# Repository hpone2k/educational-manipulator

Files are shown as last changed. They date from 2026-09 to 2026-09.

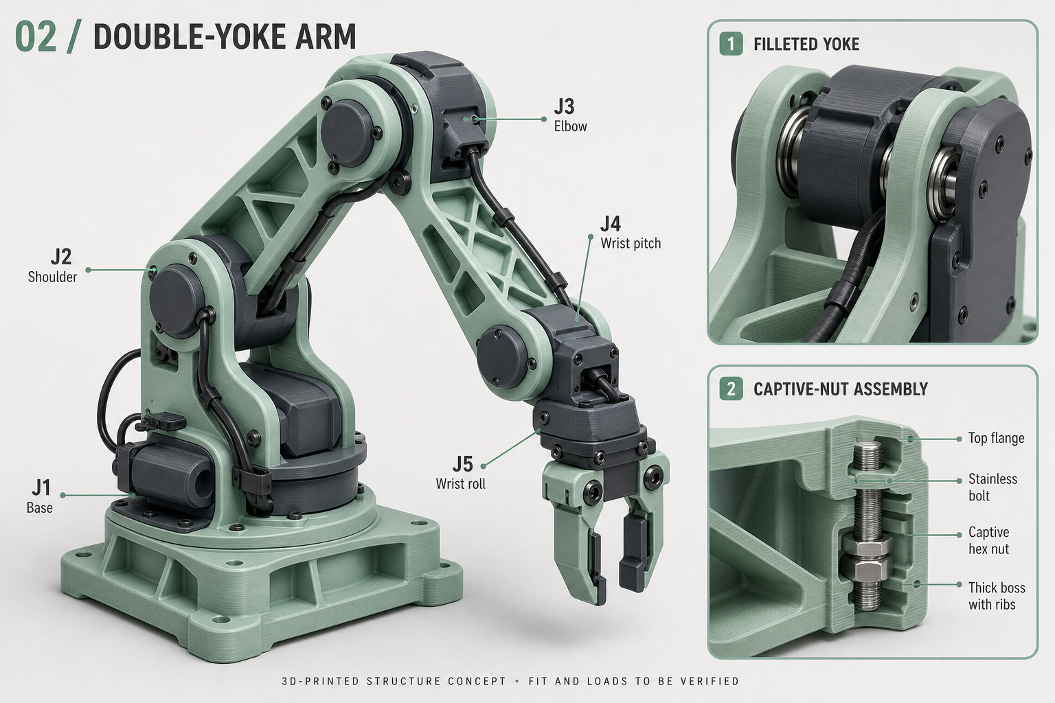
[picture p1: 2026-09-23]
design-concepts/plastic/02-double-yoke.png

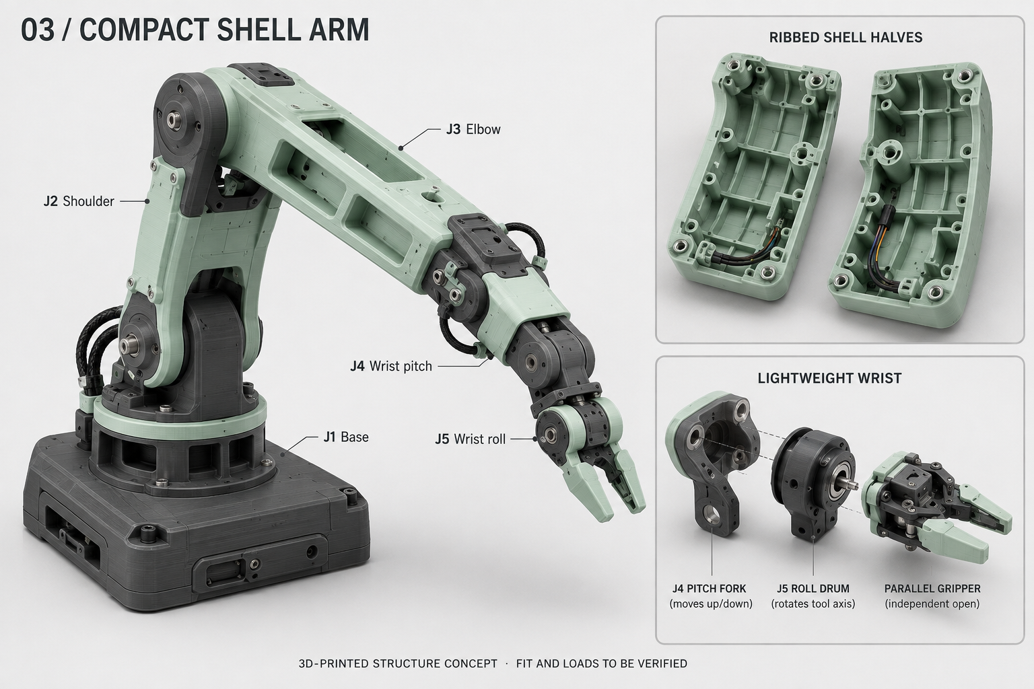
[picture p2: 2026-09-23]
design-concepts/plastic/03-compact-shell.png

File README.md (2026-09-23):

# Educational Manipulator — Blender & Web Studio

The latest mechanical prototype is **EDU06 R06**, with four AX-12A motors, two XM430-W350-T motors, five arm axes and a powered gripper. It includes paired joint supports, centred links, an enlarged electronics base and a modelled daisy-chain harness.

- [Blender assembly](cad/blender-edu06-r06/EDU06_R06.blend)
- [Complete R06 package: model, 186 STL files, previews and reports](cad/blender-edu06-r06/EDU06_R06_Blender_and_Print_Prototype.zip)
- [Assembly, dimensions and printing guide](cad/blender-edu06-r06/README.md)
- [Mechanical verification and limitations](cad/blender-edu06-r06/engineering-review.md)
- [Wiring and connector notes](cad/blender-edu06-r06/wiring-notes.md)

R06 has sampled digital geometry, motion and cable checks. Physical print fits, cable retention and load capacity still require validation. Earlier CAD revisions are retained in `cad/`; temporary generation files and local runtime caches are excluded from Git.

## Orbit web concept

The web application below is an earlier interactive concept. Its illustrative dimensions are separate from the R06 manufacturing prototype.

A local web application for exploring a five-joint educational robot arm. The interface includes a detailed 3D model, selectable joint labels, joint angle controls, a parallel gripper, preset poses, a 12-second motion demonstration, camera views and live tool coordinates.

## Run

With Node.js installed, open a terminal in this folder and run:

```sh
npm start
```

Open http://127.0.0.1:4173 in a browser with WebGL 2 support. Keep the terminal running. No package installation or external service is needed; Three.js 0.180.0 and OrbitControls are included in `vendor/`, with their MIT license. Use the local server rather than opening `index.html` directly because the page uses JavaScript modules.

## Controls

- Drag to orbit; scroll or pinch to zoom; right-drag to pan.
- Select a label, a joint on the model, or its name in the control panel.
- Move sliders or enter angles. Keyboard arrows work on the inputs.
- Use Front, Side, Top, 3D and Fit for camera positioning.
- Toggle joint labels or rotation axes.
- Try Home, Reach and Fold, or play the demonstration. Stop or Escape pauses motion at its current position; a manual adjustment also stops it.

## Model conventions

Five arm DOFs: base yaw, shoulder pitch, elbow pitch, wrist pitch and wrist roll. Gripper opening is a separate actuator. All dimensions are illustrative millimetres.

| Dimension | Value |
|---|---:|
| Shoulder height above world origin | 90 mm |
| Upper arm | 180 mm |
| Forearm | 150 mm |
| Wrist pitch to roll axis | 52 mm |
| Roll axis to tool centre | 73 mm |
| Gripper clear opening | 0–60 mm |

The displayed world frame is right-handed with Z upward. In Three.js coordinates, world X = scene X, world Y = −scene Z, world Z = scene Y. Shoulder zero is horizontal along the base's +X direction. Elbow and wrist angles are relative to their parent links. Tool position is the centre between the fingertips and is independent of wrist roll and gripper opening.

This is a kinematic concept model. It does not simulate mass, torque, collisions, gravity, motor limits or real hardware. Some manually selected poses may intersect the arm or floor. Real dimensions, joint limits and motor calibration can be added once the hardware is defined.

## Files

- `index.html`: accessible page structure.
- `styles.css`: responsive interface.
- `app.js`: Three.js geometry, joint hierarchy, labels, interaction and animation.
- `server.cjs`: local HTTP server, bound to 127.0.0.1.
- `vendor/`: pinned renderer dependencies and license.
- `check-browser.cjs`: browser checks; uses this workspace's bundled Playwright runtime and installed Microsoft Edge.
- `qa/`: screenshots used for visual inspection.

The browser checks verify forward kinematics against an independent calculation, joint and gripper controls, input clamping, camera views, demonstrations, and layouts from 320 to 1440 pixels. Reference: [Three.js documentation](https://threejs.org/docs/).

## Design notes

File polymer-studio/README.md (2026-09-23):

# Polymer Arm Studio — P03

An interactive, dimensioned five-axis plastic-arm concept based on the supplied modular servo-arm image. Open `http://127.0.0.1:4173/polymer-studio/index.html` after running `npm start` in the parent project folder. Three.js is served locally; the page needs no external account or service.

P03 restores the original dark-green ORBIT theme and adds rounded cover lips, raised shell detailing, concentric joint caps, recessed socket screws, a base nameplate, braided wiring with printed clips and strain reliefs, and more detailed generic actuators. Lighting uses a local studio reflection environment, filtered shadows, multisample antialiasing and ambient occlusion. X-ray bypasses ambient occlusion so transparent covers do not obscure the interior.

## Explore

- **Exterior:** complete plastic housings and joint covers.
- **X-ray:** transparent structural shells reveal actual modeled ribs, fastening bosses, bearings, shafts, wiring and generic motor bodies. This is a display mode, not an X-ray scan or a physical simulation.
- **Open covers:** remove the five main shell covers.
- **Separate covers:** move the covers away from their mating faces for inspection.
- **Motion:** pose all five joints and the gripper, choose a preset or play a 12-second study. Escape or manual input stops the animation.
- **Parts:** inspect nominal dimensions, focus a component, examine the M3 boss and hexagonal nut pocket, and download specification JSON or dimension CSV. In the fastening close-up, the nut is displaced along the bolt axis to expose its pocket; Fit returns to the arm.
- **Loads:** estimate static gravity moments with an adjustable payload and component mass assumptions.
- **Inspect motors:** examine a generic servo and 42 mm pancake stepper in a separate close-up. These use the same geometry as the assembled arm, including mounting ears, case seams, output horns, connectors, lead wires, laminations and end plates. Fit returns to the arm.

## Nominal dimensions

| Feature | Dimension |
|---|---|
| Base envelope | 180 × 160 × 32 mm |
| Base wall | 4 mm |
| Anchor pattern | 150 × 130 mm, four Ø6.6 mm holes |
| Shoulder axis above ground | 120 mm |
| Upper link pivot spacing | 180 mm |
| Upper link cover envelope | 232 × 52 mm; section depth 62 mm |
| Forearm pivot spacing | 150 mm |
| Forearm cover envelope | 194 × 44 mm; section depth 46 mm |
| Link walls / covers / cross ribs | 3 mm nominal |
| Wrist pitch to roll axis | 52 mm |
| Roll axis to tool centre | 78 mm |
| Gripper clear opening | 0–50 mm, measured between the inner pad faces |
| Guide rods / provisional slider bores | Ø4 mm rods, 84 mm span; Ø4.3 mm trial bores |
| Structural shaft | Ø8 mm |
| Reference 608 bearing | 8 mm ID × 22 mm OD × 7 mm width |
| Trial printed bearing seat | Ø22.2 mm × 7.2 mm depth |
| M3 bolt clearance | Ø3.4 mm |
| Printed captive-nut boss | Ø12 mm × 9 mm long |
| Hexagonal nut pocket | 5.8 mm across flats × 2.8 mm deep |
| Reference M3 nut | 5.5 mm across flats × 2.4 mm thick |

Dimensions are explicit nominal design values, not measurements of the user's hardware. Section dimensions describe the principal shell envelope and exclude exterior screw heads, joint end caps, raised face detailing, clips and cable loops. Nominal wall thickness excludes local relief and chamfers. Bearing, guide and nut allowances require print coupons and appropriate retention details. The four base feet preserve the Ø6.6 mm anchor passages.

The manufactured base, links, covers, joint supports, nut pockets and motor cradles are plastic. Motors, rolling bearings, shafts, bolts, nuts and guide rods remain separate purchased hardware. Polymer support features do not imply printed structural bolts or bearing balls.

## Mechanical scope

The model uses five serial revolute joints: base yaw, shoulder pitch, elbow pitch, wrist pitch and tool-axis roll. Gripper opening is separate. Three.js uses Y up; displayed robotics coordinates are X = scene X, Y = −scene Z, Z = scene Y.

The torque panel computes signed gravitational moments, then displays magnitudes, using τ = Σ(m g r_horizontal). Link mass is placed at each link's midpoint. Motor masses are placed at the elbow and wrist-pitch pivots. Tool mass is at the midpoint between the roll axis and tool centre; payload is at the tool centre. Values are at joint outputs and use g = 9.80665 m/s². Input masses are assumptions; they are not mesh-derived, measured or material-calibrated.

The calculation excludes acceleration, friction, transmission efficiency, cable forces, off-axis loading and compliance. It does not specify motor torque ratings or payload capacity. The scene does not solve collisions, finite-element stress, fatigue, layer adhesion, creep, bearing retention, drive couplings or printer-specific tolerances. These need actual motor data, filament and process data, load cases and physical testing.

The reference image supplies styling, not verified kinematics or dimensions. Generic motor body dimensions are 42 × 23 × 42 mm for the base stepper and 40 × 32 × 28, 32 × 26 × 24 and 24 × 20 × 20 mm for the servo representations, in scene X/Y/Z order. They exclude protruding ears, horns, connectors and shafts and do not identify compatible commercial motors. Servo internals and complete joint transmissions are not modeled. Motor mounts and output couplings require actual hardware data.

Five braided service loops update with joint poses. Their endpoints stay attached to their respective assemblies. Curves are visual routes, not a simulation of fixed cable length, minimum bend radius, slack, fatigue, stiffness or collisions. These must be engineered before fabrication.

This page does not replace the earlier Blender file or STL set, and does not claim those files match this P03 model. Visual detail does not imply NASA certification, production qualification, printable watertight CAD solids, or demonstrated load capacity.

## Sources

- [SKF 608 manufacturer datasheet](https://docs.rs-online.com/9931/A700000008717780.pdf): bearing envelope.
- [Accu M3 DIN 934 nut](https://www.accu.co.uk/hexagon-nuts/766485-NUT930M3C): across-flats size and thickness.
- All shell dimensions, clearances and mass assumptions are provisional design choices in `spec.js`.

## Files and validation

`spec.js` contains the nominal dimensions, joint ranges, forward kinematics and static torque calculation. `model.js` builds the meshes and inspection states. `studio.js` provides interaction, labels, camera controls and exports. `studio.css` and `index.html` implement the responsive page.

`check.cjs` runs browser checks using this machine's bundled Playwright and installed Edge. It checks the renderer, interior geometry, inspection controls, joint coordinates, roll and gripper independence, cable attachment errors, clamping, payload moment changes, dimension tables, motor and fastening close-ups, exports, camera views and responsive widths from 320 to 1440 px. Screenshots are in `qa/`. `mechanics-check.mjs` independently checks the gravity calculation.

The rendering add-ons are pinned to the same Three.js r180 version as the existing local core. `vendor-rendering.cjs` fetches them from the official Three.js repository; `../vendor/THREE-LICENSE.txt` contains their MIT license. Runtime rendering does not contact a CDN.

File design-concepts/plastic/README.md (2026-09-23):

# Printed-plastic manipulator concepts

Generated with the built-in image-generation tool. Exact prompts are saved in [prompts.json](prompts.json).

- [01 — Ribbed box-link arm](01-ribbed-box-link.png)
- [02 — Double-yoke arm](02-double-yoke.png)
- [03 — Compact shell arm](03-compact-shell.png)

These replace the earlier metal/hybrid styling direction with printed-plastic custom structural parts: base, links, joint brackets, covers, motor mounts and gripper fingers. Motors, bearing races, shafts, screws, nuts and guide rods remain purchased hardware.

The images explore deeper link sections, internal ribs, generous joint-root fillets, double-supported pivots, reinforced fastener bosses and cable routing. They are generated visual studies, not CAD assemblies or verified engineering diagrams. Some illustrative joint labels, fasteners and inset details may be imprecise. Five-axis kinematics, detailed interfaces, print orientation, tolerances, layer-direction strength, creep, deflection, motor torque and base anchoring must be established in the actual design. No load rating is implied.

The existing Blender file and STLs have not been changed by this image-generation step.

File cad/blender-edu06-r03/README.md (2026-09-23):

# EDU06 R03 — printed six-axis manipulator

Open **`EDU06_R03.blend`** in Blender. It contains the assembled arm, seven dimensioned actuator references, individually named printed parts, an open service base and a geared gripper. J1 and the wrist use AX-12A motors; J2/J3 use XM430-W350-T motors. The gripper has its own AX-12A actuator.

This is an editable engineering prototype. Geometric checks, movement demonstrations and calculated loads are documented separately; the arm has no certified payload or completed physical load test.

## Move and inspect the model

1. Select **`CONTROL • angles in degrees — edit custom properties`** in the Outliner.
2. Open **Object Properties → Custom Properties**. Change `J1` through `J6` for the six joint output angles; `GRIP` controls the geared jaw opening angle. Values are degrees.
3. Press **Space** over the Timeline to play the **360-frame / 12-second** demonstration. Stop playback before editing a pose. Existing animation keys restore their recorded values when you change frames; insert your own property keyframes if you want to keep an edited animation.

Gear drivers impose actual modeled reductions of **3:1 at J1, 4:1 at J2 and 3:1 at J3**. The gripper's two gears rotate oppositely. This is a kinematic rig: animation does not simulate motor heating, printed-bearing friction or structural failure. Use the documented angle ranges, then review the motion-check results before extending them.

Orbit with the middle mouse button, pan with Shift + middle mouse, and zoom with the wheel. Press **Numpad 0** to leave the saved camera view. Select a part and use **Numpad .** to frame it. Switch to **Solid** viewport shading, then **Alt + Z** toggles X-ray for internal inspection; the Outliner eye icons let you hide the lid, frame or other components without deleting them.

## Identify the parts

| Collection | Contents |
|---|---|
| `01 PRINTED PARTS` | Individual manufacturing meshes: structure, gears, plain bearings, shafts, cradles, caps and spacers |
| `02 PURCHASED` | Motor envelopes/horns, nuts, screws and electronics; exclude these from printing |
| `03 JOINT CONTROLS` | Joint datums, drivers and the main control object |
| `04 CABLE ROUTING` | Visual cable paths; real cable access and service loops need fitting |
| `05 STUDIO` | Presentation elements; exclude from printing |

Green and ivory materials distinguish the printed components. Black motor bodies and electronic modules are reference hardware. The fabricated design adds no metal bearing, shaft, guide rod or structural bracket; the motors retain their supplied internal hardware and horns.

## Print the fit samples first

The scene uses **millimetres**. STL files in `prototype_stl/` also use millimetres; import them into Bambu Studio at **100% scale**. Do not print a single export of the assembled arm.

Start with `F01_hole_and_nut_coupon.stl`, `F02_AX_16PCD_horn_coupon.stl` and `F02_XM_16PCD_horn_coupon.stl`. Then try one motor cradle/cap/shim set and one printed journal/bushing pair. Check actual motors, screws and nuts with calipers before committing to the full set. Thin spacers and 0.30 mm shims need suitable layer settings and a measured result.

The STL audit compares part bounds against the Bambu A1's **256 × 256 × 256 mm** build volume. Check the final sliced orientation, supports, brim and plate exclusions in Bambu Studio. Closed meshes and build-volume fit do not establish layer strength or support-free printability.

## Read the verification and assembly records

- **`engineering-review.md`** — completed checks, design decisions and remaining physical validation.
- **`motor-and-fastener-guide.md`** — exact motor datums, horn screws, rear-inserted cradle bolts, spacers and assembly sequence.
- **`structural-fasteners.md`** — remaining structural screw/nut sets and matching holes, including the elbow bearing ties.
- **`motor-interface-schedule.json`** — the generated interface and fastener stack for each actuator.
- **`stl-audit.json`** — independent checks of the exported STL files.
- **`mass-load-audit.json`** — mass and joint-moment calculations with their assumptions.
- **`demo-trajectory-audit.json`** — sampled clearances along the saved animation, when supplied.

The scene selector also contains **Individual print parts**, a layout of the separate exported meshes. It is an inspection layout, not a prepared multi-plate slicing job. The PNG previews and motion GIF are rendered from the editable Blender geometry.

Keep the open-base service access and printed 8 mm feet when assembling the base. Establish secure mounting, free movement and cable clearance before staged powered testing. Review the calculated loads and the remaining checks before assigning a payload.

## Edit and regenerate

Save a separate copy before manual editing. The source generator is `build_edu06.py`, with reusable geometry in `blender_lib.py`, motor interfaces in `motor_models.py` and gear mathematics in `gear_math.py`. Run the generator in a separate background Blender process to avoid disturbing an unsaved scene:

```text
blender --background --python build_edu06.py
```

Regeneration overwrites the generated R03 model and outputs. Re-run the mesh, motion and load checks after dimensional or kinematic changes; previous results do not validate a modified design.

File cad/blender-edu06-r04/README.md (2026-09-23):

# EDU06 R04 — centred wrist and parallel gripper

Open **EDU06_R04.blend**. This revision replaces the sideways wrist adapters with an aligned roll–pitch–roll assembly and larger parallel fingers. The green/ivory render is produced from this editable assembly. R03 is preserved in its separate folder.

## Inspect and move

The saved engineering scene shows the assembled robot. Select the **CONTROL** object and expand **Object Properties → Custom Properties**. J1–J6 are output angles in degrees. **GRIP is the clear jaw opening in millimetres**, from 20 to 70 mm. Space plays the 360-frame demonstration; stop playback before editing. Keyframed values return as the timeline moves. NumPad 0 leaves/enters the camera view; middle-mouse orbits. In Solid shading, Alt+Z toggles X-ray.

The second scene, **Individual print parts**, separates the printable components on a display grid. It is an inspection layout, not a single slicer plate. Collection 01 contains printable parts; motors, screws, nuts, electronics, cables and presentation objects are excluded from STL export.

## Main dimensions

| Interface | Nominal CAD dimension |
|---|---:|
| AX-12A published envelope | 32 × 50 × 40 mm |
| XM430 published main case | 28.5 × 46.5 × 34 mm; projections modelled separately |
| Shoulder–elbow pivot spacing | 100 mm |
| J4 roll datum–J5 pitch datum | 78 mm |
| J5 pitch datum–J6 horn datum | 41 mm |
| J6 horn–gripper horn datum | 74.45 mm |
| Neutral J4 datum–gripper tip plane | 293.45 mm |
| Finger body, each | 75 × 24 × 12 mm, lightened with open rear pockets |
| Replaceable contact pad thickness | 3 mm, with 1.2 mm-deep central V |
| Clear parallel opening | 20–70 mm |
| Roll journal / fixed bore | Ø40 / Ø40.5 mm; 16 mm nominal sleeve length |
| Pitch trunnion / fixed bore | Ø20 / Ø20.5 mm |
| M2 / M3 printed clearance trials | Ø2.3 / Ø3.4 mm |
| M3 captive-nut trial | 5.8 mm across flats, 2.8–2.9 mm depth |

These are model dimensions, not a promise of as-printed accuracy. Flat lands contact rectangular objects; the shallow V helps locate round ones within the opening range. Grip force and slip depend on the printed surfaces and object. No universal tool capacity is assigned.

## Motors and reductions

| Axis | Motor | External drive | Declared output travel |
|---|---|---|---:|
| J1 base yaw | AX-12A | 20/60 teeth, module 1.5, 3:1 | −40°…+40° |
| J2 shoulder pitch | XM430-W350-T | 20/100, module 1.25, 5:1 | 60°…85° |
| J3 elbow pitch | XM430-W350-T | 20/80, module 1.25, 4:1 | 30°…75° |
| J4 forearm roll | AX-12A | Direct, external printed support | −40°…+40° |
| J5 wrist pitch | AX-12A | 20/60, module 1.5, 3:1 | −25°…+25° |
| J6 tool roll | AX-12A | Direct, external printed support | −60°…+60° |
| Gripper | AX-12A | 20T, module 1.5 pinion; opposing racks | 20–70 mm gap |

The six arm axes use six motors; the gripper uses a seventh. The elbow's fixed gearbox is clocked 90° away from the shoulder; its output zero is unchanged. Gear profiles use 20° involutes and explicit nominal backlash. The motor phase shown by a Blender driver is not a calibrated hardware goal-position command.

The shoulder's 60° lower operating limit follows the gravity calculation for the larger gripper. More extended poses exceeded the motor planning comparison. These operating limits constrain the prototype's workspace; they are not a physical payload certification.

Actual ROBOTIS exterior CAD supplies motor cases, connector geometry, body holes and stock horns. Details and the XM drawing/STEP revision discrepancy are in `motor-references/README-official-cad.md`. Printed cradles capture the cases; fabricated parts do not rely on guessed motor-body drilling positions. Supplied horns and their original retention hardware remain part of the purchased motors.

## Assembly order for the new wrist

1. Print fit coupons first. Check the actual screws, nuts, horn pattern and clearances against your motors.
2. Capture J4 in its keyed cradle on the forearm. Fit its printed annular output and M2 × 6 horn screws. Fit four flange nuts before installing the centred fork with M3 × 10 screws. The central opening preserves horn-screw access before downstream components are added.
3. Install the J5 motor in the fork. Install its pinion and M2 × 6 horn screws before the removable outboard journal bridge. Fit the matching printed foot/head spacers and M3 × 70 bridge fasteners.
4. Place the moving J6 carrier inside the fork. Insert the two separate printed trunnions from the sides, then fasten each with four M3 × 20 screws into its captured nuts. The journals have running clearance; tightening their screws must not clamp the fixed cheeks. Add the 60T gear using its recessed M3 × 12 seats.
5. Capture J6, then assemble its annular output and gripper rear palm while the gripper motor is absent. Fit the output horn screws through the central access opening. Four PCD 48 palm screws use **1 mm printed spacers and M3 × 12 screws** so their tips clear the fixed roll sleeve.
6. Insert the gripper's rear cradle nuts before mating its palm. Install the gripper motor from the front and use the recessed **M3 × 45 front-inserted cradle screws**. These replace inaccessible rear screw heads.
7. Fit the gripper's rear-to-front standoffs, lower rails and pinion. Lower the opposed carriages into the rails from above, then install the retaining lips and journal bridge. End stops prevent insertion from the rail ends. Attach the thick fingers, slide in their keyed pads, and install the removable tip stops.

The exact added screw/nut quantities are in `hardware-bom.json`. Printed spacers are separate parts. No added metal bearing, rod, bracket, insert, spring or rubber pad is assumed. Connector service loops remain visual routing references; actual cables require clearance checks throughout motion.

## Printing and commissioning

All exported parts use millimetres and are checked against the A1's 256 mm nominal build cube. Print one part or a deliberate slicer arrangement, not the assembled robot. Leave room for brim and printer exclusions. PLA is a provisional interpretation of “normal filament”; measure printed mass and fit before accepting the model's assumptions.

Begin with the hole/nut and horn coupons, then one motor cradle and one bearing fit. Gears normally print flat with their axes vertical. Finger pockets and T slots should face upward in the supplied print orientation. Large yokes and the open case require slicer support/orientation review. Load-bearing perimeters, layer direction, creep, motor heat and tooth strength have not been qualified by a material test.

Start any physical assembly unpowered and turn every joint through its allowed range by hand. Investigate binding before powering motors. Blender playback checks geometry and kinematics; it does not measure dry polymer friction, real backlash, print strength or motor temperature. The separate U2D2 is a communication interface and does not power the motors.

Read **engineering-review.md** for the actual geometry checks, torque assumptions and release limitations. This is an editable, dimensioned engineering prototype; a physical payload rating remains unassigned.

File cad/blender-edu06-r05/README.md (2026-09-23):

# EDU06 R05 — six motors, curved upper structure

Open **EDU06_R05.blend**. This revision uses exactly **four AX-12A and two XM430-W350-T motors**. Five motors position the arm; the sixth opens and closes the gripper. It has **five arm DOF plus one gripper coordinate**. The earlier separate forearm-roll motor is removed. R04 is preserved in its own folder.

The base enclosure, turntable and yaw drive retain the R04 design. Above the base, rounded outlines, open motor saddles, curved bearing supports and oval reliefs replace the box-like shapes. The shorter wrist has a fixed forearm flange, geared pitch and supported tool roll. These shapes are printable structure, not decorative covers.

## Motors and motion

| Control | Motor | Drive | Configured travel |
|---|---|---|---|
| J1 — base yaw | AX-12A | 20/60 teeth, module 1.5, 3:1 | −40°…40° |
| J2 — shoulder pitch | XM430-W350-T | 20/100, module 1.25, 5:1 | 45°…90° |
| J3 — elbow pitch | XM430-W350-T | 20/80, module 1.25, 4:1 | 30°…75° |
| J4 — wrist pitch | AX-12A | 20/60, module 1.5, 3:1 | −25°…25° |
| J5 — tool roll | AX-12A | Direct, external printed support | −60°…60° |
| GRIP — jaw opening | AX-12A | 20T pinion and opposed racks | 20–70 mm clear gap |

Gear reduction increases output torque while reducing speed and angular travel. It does not eliminate printed-bearing friction. Blender motor phases are kinematic relationships, not calibrated hardware position commands.

Select **CONTROL** and expand **Object Properties → Custom Properties**. J1–J5 are output angles in degrees; GRIP is the clear opening in millimetres. Space plays the 360-frame demonstration. Stop playback before editing; moving the timeline reapplies its keyframes. NumPad 0 enters/leaves camera view. Middle-mouse orbits; in Solid shading, Alt+Z toggles X-ray.

The **Individual print parts** scene displays the separate printable components. It is an inspection grid, not a slicer plate. Collection 01 contains printable geometry; motors, screws, nuts, cables, electronics and studio objects are excluded from STL export.

## Dimensions and interfaces

All CAD and STL dimensions are millimetres. Actual ROBOTIS exterior STEP geometry supplies motor bodies, connector shapes, body holes and stock horns. See **motor-references/README-official-cad.md** for source drawings, datums and the XM STEP/drawing discrepancy. The cradles capture the cases rather than relying on guessed body-hole positions.

AX-12A published envelope: 32 × 50 × 40 mm. XM430 main case: 28.5 × 46.5 × 34 mm, with horn/idler projections modelled separately. Shoulder–elbow pivot spacing: 100 mm.

The fixed forearm flange has a 60 mm outside diameter, 26 mm central access opening, 10 mm axial thickness and four M3 holes on a 48 mm pitch circle. Captive nuts enter radially. The mating 5 mm wrist heel uses front-inserted M3 × 12 screws.

The gripper retains 75 × 24 × 12 mm finger bodies, lightened behind the contact surfaces, with separate 3 mm keyed pads. Flat lands contact rectangular objects; a shallow V helps locate round objects within the 20–70 mm opening. Shape does not establish grip force or slip resistance.

Provisional running fits: roll journal/bore Ø40/Ø40.5 mm; pitch trunnion/bore Ø20/Ø20.5 mm. M2/M3 clearance trials: Ø2.3/Ø3.4 mm. M3 captive pockets: 5.8 mm across flats. Print coupons and compare them with actual filament, nuts, screws and motor revision.

**wrist-dimensions.json** gives final wrist datums. **print-parts.csv** lists exported parts, bounds and solid-PLA mass estimates. **hardware-bom.csv** lists added screws/nuts; factory hardware supplied with motors is separate. Detailed mounting stacks are in **motor-interface-schedule.json** and **hardware-bom.json**.

## Assembly sequence

1. Print the hole/nut and motor-horn coupons. Check a cradle and a printed journal fit before committing to all parts.
2. Assemble the unchanged base, printed yaw bearings, geared shoulder and elbow. Their external output bearings carry bending loads independently of the motor horns.
3. Insert four M3 nuts radially into the fixed forearm flange. Attach the wrist heel with front-inserted M3 × 12 screws. Keep the central opening accessible.
4. Assemble the J5 tool-roll motor, rear capture plate and supported sleeve as a separate moving unit. Tighten its rear screws before sliding the unit into the fixed fork. Insert the two trunnions from the sides and fasten them; they must clamp the moving unit without locking the stationary cheeks.
5. Install the 60T pitch wheel and fixed J4 motor/pinion. Tighten the motor's rear screws from the open back, then install its removable pinion journal bridge. Attach the gripper rear palm while its own motor is absent, preserving straight driver access to roll horn and palm screws.
6. Insert the gripper captive nuts and motor. Its cradle screws enter from the front. Assemble rails, pinion and opposed carriages; install removable guide lips after inserting the slides.
7. Attach the fingers, slide in the keyed pads and install tip stops. Check travel, end stops and free movement by hand before powering.

Printed structures, gears, shafts, sleeves, spacers and pads require no additional metal brackets, bearings, rods, inserts or springs. Motors retain their supplied components. Cable routes are visual references; actual wires need service loops and motion clearance checks. U2D2 provides communication, not motor power.

## Printing and validation

Exported part bounds are checked individually against the A1's nominal 256 mm build cube. Leave room for brims and printer exclusions. PLA is a provisional interpretation of “normal filament”; measured mass, layer adhesion, creep and heat resistance can differ from assumptions.

Gears normally print flat with their axes vertical. Review support and layer direction for yokes, slides and the base. Print fit coupons first.

Read **engineering-review.md** and the JSON reports for this revision's actual results. Discrete collision samples and gear checks do not establish continuous cable clearance, strength, dry-bearing friction, thermal duty cycle or a physical payload rating. This is a dimensioned engineering prototype. Begin commissioning unpowered, then unloaded, and measure friction, deflection and temperature before assigning carrying capacity.

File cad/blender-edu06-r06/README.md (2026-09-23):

# EDU06 R06 — centred, bilateral printed arm

Open **EDU06_R06.blend**. This prototype uses exactly **four AX-12A and two XM430-W350-T motors**: five arm axes plus a powered gripper. It has **five arm DOF and one jaw-opening coordinate**, not six independently controlled arm axes.

R06 supports the upper arm and forearm from both sides. Each geared joint has an independent printed output shaft, front bolted flange and positively keyed rear flange. Matched curved side plates connect these outputs, replacing the previous offset link arrangement. Shoulder–elbow pivot spacing is **100 mm** with no lateral centre offset; the wrist mounts to a removable crossmember centred between the forearm plates. These printed journals carry bending around the motor output; their friction and load capacity still require physical testing.

## Inspect and move the model

Select **CONTROL**, then **Object Properties → Custom Properties**. J1–J5 are output angles in degrees; GRIP is the clear jaw gap in millimetres. Space plays the 360-frame demonstration. Stop playback before editing a control: changing frames reapplies its keyframes. Middle-mouse orbits, NumPad 0 toggles camera view, and Alt+Z toggles X-ray in Solid shading.

The **Individual print parts** scene is an inspection grid, not a slicer plate. Collection 01 contains printable parts. Purchased motor references, screws, nuts, electronics, cables, reservation boxes and studio objects are not printed.

| Control | Motor | Drive | Configured travel |
|---|---|---|---|
| J1 — base yaw | AX-12A | 20/60 teeth, module 1.5; 3:1 | −40°…40° |
| J2 — shoulder pitch | XM430-W350-T | 20/100, module 1.25; 5:1 | 45°…90° |
| J3 — elbow pitch | XM430-W350-T | 20/80, module 1.25; 4:1 | 30°…75° |
| J4 — wrist pitch | AX-12A | 20/60, module 1.5; 3:1 | −25°…25° |
| J5 — tool roll | AX-12A | Direct, with external printed support | −60°…60° |
| GRIP — jaw opening | AX-12A | 20T pinion and opposed racks | 20–70 mm |

Reduction trades speed and travel for output torque. Blender's gear phases are kinematic relationships; they are not calibrated hardware position commands.

## Dimensions and service space

All model and STL dimensions are **millimetres**. Official ROBOTIS exterior STEP geometry supplies motor bodies, stock horns and connector shapes. The cases are mechanically captured by printed cradles; no guessed motor-body hole pattern is used. AX-12A's published envelope is **32 × 50 × 40 mm**; the XM430 main case is **28.5 × 46.5 × 34 mm**, with projections modelled separately. See [motor CAD sources and datums](motor-references/README-official-cad.md).

- **Base:** measured maximum enclosure **241 × 240 × 95 mm**, plus 8 mm printed feet. The nominal shell/lid footprint is 240 × 240 mm; front-panel support arms add 0.5 mm on each side. The open front has a removable panel, and the structural lid removes for drive access. The original yaw centre at X = −28 mm, gear elevations and pedestal mounting interface are retained.
- **Controller bay:** 100 × 65 × 30 mm of reserved clear space above a removable slotted tray. It accommodates a controller-sized envelope without assuming an Arduino mounting-hole pattern. Choose standoffs and screw lengths from the actual board.
- **U2D2:** a separate **48 × 18 × 14.9 mm** reference, retained by its own tray and removable printed strap. USB plug withdrawal space, rear cable outlets and screw-fastened split cable saddles are provided. The larger controller bay is additional space; the U2D2 itself is small.
- **Power hardware:** a separate 45 × 35 × 22 mm reserved envelope and slotted plate. Its actual board, fuse, terminals, supply and current rating remain unselected.
- **Wrist interface:** the flange front datum is **X = 78.8 mm from the elbow pivot**, centred at Y = Z = 0 in the forearm frame. Its Ø60 mm neck joins the crossmember behind the wrist gear sweep; the front has Ø26 mm central access and four M3 holes on a Ø48 mm pitch circle. A 5 mm wrist heel bolts to it from the front.
- **Gripper:** 75 × 24 × 12 mm finger bodies with lightening pockets, separate 3 mm keyed pads, flat contact lands and a shallow V. Shape and opening range do not establish grip force or slip resistance.

[base-layout.json](base-layout.json) records the clear bays and installed panel transform; [wrist-dimensions.json](wrist-dimensions.json) and [gripper-design-notes.json](gripper-design-notes.json) record local datums and assembly details. Use [motor-interface-schedule.json](motor-interface-schedule.json), [hardware-bom.json](hardware-bom.json) and the generated CSVs to identify the actual fastener stacks.

## Assembly order

1. Print the hole/nut and AX/XM horn coupons. Measure the supplied motors and hardware; trial-fit a cradle, gear mesh, journal and slide before printing the complete set.
2. Install the base feet, lower yaw support, printed shaft/bushings and motor drive. Fit the trays and actual electronics with the front panel removed. Leave the lid open while checking connectors and cable access.
3. Preload captive nuts before closing their access. Assemble the shoulder's fixed cheeks, sleeves, independent output shaft and keyed rear flange. Fit both upper-arm plates with their front spacers and rear bolts. The central retainer must clamp the rotating shaft/flange stack while preserving clearance to stationary cheeks.
4. Build the elbow reducer on its own fixed cheek ties. Attach its outer mounting ears to both upper-arm plates through the separate support posts. Fit both forearm plates to the elbow's front and keyed rear outputs, then bolt the centred wrist crossmember between their ends.
5. Load the wrist-flange nuts and attach the empty wrist heel using four front-inserted M3 × 12 screws. Preassemble and tighten the J5 motor/carrier before inserting it into the pitch fork. Install its removable side trunnions, pitch gear and J4 drive; fit the pinion journal bridge last.
6. Attach the gripper palm through its four printed service-gap posts, keeping its motor absent so the roll horn and palm screws remain accessible. Route the AX leads through the rear connector passage and open gap before installing the front-loaded motor. Then fit the pinion, carriages and removable guide lips; attach fingers, slide in pads and secure the tip stops.
7. Route and secure the actual harness, then move every joint and the gripper by hand with power off. Check bearing freedom, nut retention, cable slack and tooth clearance before fitting the lid and service panel.

All custom brackets, gears, shafts, sleeves, spacers and pads are printed. Purchased motors retain their factory components; additional mechanical metal is screws and nuts. U2D2 provides communication, **not motor power**. Read [wiring-notes.md](wiring-notes.md) for the separate supply, AX/XM connector conversion, mixed protocols and provisional harness assumptions.

The gripper harness also has supplementary bend and strand-spacing checks across 275 wrist combinations; see [wiring-evidence.md](wiring-evidence.md). Its guide points remain routing references pending physical cable fitting and retention.

## Print and commission

Import individual **prototype_stl/** files into Bambu Studio in millimetres. The largest case STL is 241 × 240 mm and the lid is 240 × 240 mm; leave room within the A1's nominal 256 mm plate for the selected brim and printer exclusions. Preview every plate, support interface and hole rather than treating the Blender inspection layout as a print job. Gears normally print flat with their axes vertical; inspect layer direction and supports for the forks, base, fingers and slides.

PLA is a provisional interpretation of “normal filament.” Trial dimensions include Ø2.3/Ø3.4 mm M2/M3 clearances, 5.8 mm across-flats M3 nut pockets and 0.25 mm radial journal clearance. Actual filament, layer orientation, shrinkage and hardware variation govern final fits. Exported solid-PLA mass estimates are not slicer or weighed masses.

Consult [engineering-review.md](engineering-review.md) and this revision's dated mesh, gear, motion, wiring and mass/load reports for the recorded results and their scope; earlier revision checks do not validate new parts. Discrete collision checks and a moving Blender model do not establish continuous cable clearance, strength, friction, heat limits or a physical payload rating. Commission unloaded first and measure deflection, joint friction and motor temperature before assigning an operating load or duty cycle.

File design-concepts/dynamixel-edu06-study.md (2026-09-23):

# EDU-06 DYNAMIXEL concept — 23 September 2026

This is an image-led design study, not a verified CAD assembly or a printable file. Motor casings, gear engagement, tooth counts, axis packaging and clearances in the AI illustration are approximate. Use the intended architecture below rather than taking dimensions or gear tooth counts from the image.

## Joint assignment
Six independent arm axes, with gripper opening separate:
- J1 base yaw: AX-12A, proposed external 3:1 spur reduction.
- J2 shoulder pitch: XM430-W350-T, proposed external 4:1 reduction.
- J3 elbow pitch: XM430-W350-T, proposed external 2:1 reduction.
- J4 forearm roll: AX-12A.
- J5 wrist pitch: AX-12A.
- J6 tool roll: AX-12A.
- G gripper: additional AX-12A, central pinion driving two opposed racks on supported parallel guides.
Total: five AX-12A + two XM430-W350-T. If the gripper is counted as the sixth actuator, that would instead be five arm axes plus gripper.

## Proposed construction
Short ribbed plastic links, split covers, captive metal nuts, bearing-supported shafts, bolted base and printed motor brackets tailored separately to AX and XM mounting patterns. All custom structural parts and external gears are intended to be printed; motors, shafts, bearings, nuts, bolts and guide rails remain purchased hardware. Filament, print orientation, tooth strength, creep, fit and fastening details remain open.

Upper-arm and forearm pivot spacings: 140 and 120 mm. Preliminary distal assembly extends another 150 mm to the tool centre; horizontal shoulder-to-tool distance approximately410 mm. These are proposed study dimensions, not dimensions extracted from the image.

The base turntable bearing carries weight and overturning moment; it does not eliminate the overturning load. Gearing trades speed/travel for torque and introduces losses and backlash. Bearing selection must check axial/radial load, overturning moment, stiffness, mounting and preload. A simple turntable product without a moment rating is not yet selected.

An illustrative base gear layout is module2, 20-tooth pinion and60-tooth externally toothed driven gear: pitch diameters40 and120 mm, shaft centres80 mm. Both axes vertical and gears coplanar, small gear outside the large gear. Final gear guard and bolt clearance may enlarge the nominal220x200 mm base. The generated image's other tooth-count/diameter text is not a released gear specification.

AX-12A position travel is300 degrees: external3:1 base reduction leaves at most100 degrees total base travel, before mechanical/cable restrictions. Wider travel requires a different control architecture, e.g. external output sensing and a homed closed-loop controller with wheel mode. Wheel mode alone does not retain joint-mode position control. Do not promise360-degree positioning from the standard servo encoder through this reduction.

## Preliminary moment calculation
Horizontal straight-arm screening case, gravity9.80665 m/s². Below are assumed lumped component masses and horizontal positions from J2. Servo masses use manufacturer data; structure/transmission/hardware mass budgets are provisional targets and must be replaced by CAD/measured masses. The wrist frame is lumped near J5. This is not an all-pose load envelope.

| Assumed lump | Mass kg | Horizontal position from J2 m |
|---|---:|---:|
| upper | 0.1 | 0.07 |
| elbow | 0.082 | 0.14 |
| forearm | 0.08 | 0.2 |
| AX4 | 0.0546 | 0.26 |
| AX5 | 0.0546 | 0.295 |
| AX6 | 0.0546 | 0.33 |
| AXg | 0.0546 | 0.36 |
| wrist frame | 0.06 | 0.3 |
| gripper | 0.04 | 0.385 |
| payload | 0.1 | 0.41 |

Total distal mass including100 g payload:0.6804 kg.
- J2 static gravity moment:1.734 N·m.
- J3 static gravity moment:0.869 N·m.
- J5 approximate static pitch moment:0.205 N·m.
- J1 vertical yaw has no gravity torque in this ideal stationary case, but the turntable and base structure carry approximately1.734 N·m overturning moment plus the remaining support loads. Yaw drive sizing also needs rotational inertia, acceleration, bearing friction and cable resistance.
- J4/J6 roll moments depend on off-axis centre of gravity and tool orientation; they are not validated by this planar screening calculation.

Manufacturer estimated continuous torque is0.82 N·m XM430-W350-T and0.30 N·m AX-12A, estimated as20% of stall, not a guaranteed application rating.
Assuming80% efficiency for each complete external reduction:
- J2 motor requirement1.734/(4x0.8)=0.542 N·m; estimated joint screening torque0.82x4x0.8=2.624 N·m.
- J3 motor requirement0.869/(2x0.8)=0.543 N·m; estimated joint screening torque0.82x2x0.8=1.312 N·m.
- J5 direct-drive requirement approximately0.205 N·m versus estimated0.30 N·m.
These imply only about1.5 times static headroom in this mass scenario. They exclude acceleration, impacts, wire loads, heavier actual prints, thermal enclosure effects, structural deflection and gear durability. No validated payload rating follows. The100 g figure is a study assumption; not a lifting claim.

Added gear ratios reduce output speed; shoulder/elbow ranges and homing need to be designed around XM430 operating modes. Keep the distal AX motors and gripper compact; adding distal mass is costly at J2. Spring assistance is an optional later study, not credited in these calculations.

## Electrical considerations
AX-12A and XM430-W350-T are TTL smart servos, not steppers. A regulated12 V bus is within both published voltage ranges, but12 V is the AX maximum; do not connect AX motors directly to a fully charged3S pack at12.6 V. Confirm supply behavior and wiring. AX uses Protocol1.0; the XM supports configurable protocol options. Use compatible correctly pinned conversion cables; model mounting patterns/connectors are not interchangeable.

## Primary references
- AX specifications, mass, travel and voltage: https://emanual.robotis.com/docs/en/dxl/ax/ax-12a/
- XM specifications, mass, dimensions, stall torque and modes: https://emanual.robotis.com/docs/en/dxl/x/xm430-w350/
- AX estimated continuous torque disclosure: https://robotis.us/products/dynamixel-ax-12a
- XM estimated continuous torque disclosure: https://robotis.us/products/dynamixel-xm430-w350-t

At12 V the e-manual stall figures are1.5 N·m for AX and4.1 N·m for XM. Stall torque is not continuous lifting capability. The current AX US storefront contains an inconsistent stall field; this note uses the AX e-manual's1.5 N·m figure and identifies the storefront's0.30 N·m continuous figure as an estimate.

## Image
Generated with the built-in image-generation tool. Initial generation prompt: dynamixel-edu06-prompt.txt. Refined to clarify base external gearing, wrist roll and gripper racks. Image mechanisms remain illustrative; CAD geometry must establish actual meshes, axes, shaft support and interference before fabrication.

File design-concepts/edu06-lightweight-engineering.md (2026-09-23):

# EDU-06 L01: lightweight PLA engineering study
23 September 2026. Supersedes the 140 / 120 mm link-length assumption in the earlier image study. The image and existing five-axis webpage have not been converted to dimensional CAD. This revision defines engineering inputs; it does not release printable arm parts.

## Baseline
User: normal filament, Bambu printer. Working assumption: standard PLA, 0.4 mm nozzle. Exact printer, nozzle and filament formulation remain unconfirmed. Retain six arm axes plus separate geared gripper: 5 x AX-12A and 2 x XM430-W350-T.

| Motor | Manufacturer W x H x D | Mass | Count |
|---|---|---:|---:|
| AX-12A | 32 x 50 x 40 mm | 54.6 g | 5 |
| XM430-W350-T | 28.5 x 46.5 x 34 mm | 82 g | 2 |

Total motors: 437 g. J4/J5/J6/gripper AX motors alone: 218.4 g. This makes a tiny, weightless wrist impossible. Bodies are positioning envelopes, not installation clearances: allow for horns, mating cables, screw heads, moving yokes and tool access. Preliminary pocket allowance is 0.25-0.40 mm per side, to be tuned on coupons; do not add it to hole-center coordinates.

## Mounting drawings actually inspected
AX: official ROBOTIS front/side image saved in motor-references/ax-12a-dimensions.png.
XM: ROBOTIS-authored XM series datasheet, hosted by Distrelec, saved in motor-references/robotis-xm-datasheet.pdf. This is a reference drawing, not confirmation of the revision of the user's horn.

- AX output horn: four M2 tapped holes at 90-degree intervals on a 16 mm pitch circle; drawing callout depth 4.0 mm. In front-view coordinates centred on the output axis, cardinal hole centres are (+8,0), (0,+8), (-8,0), (0,-8) mm. Frame hole clearance is separate from the motor's M2 thread.
- AX front body mounting rows: drawing shows 27 mm between the two outer mounting-hole columns and 8 mm vertical pitch between repeated rows. The top repeated row is 6.5 mm below output centre. Do not mistake the case assembly screws for all-purpose bracket mount holes. AX body frame mounting hardware and nut access must be matched to the official assembly scheme; no body-hole coordinates are released for fabrication here.
- XM chosen four-hole side interface: rectangular 12 x 24 mm hole spacing, M2.5 x 0.45 tapped holes, maximum depth 3.0 mm in the inspected sheet. Local pattern coordinates around that pattern's centre are (+/-6,+/-12) mm. The pattern centre is NOT the output-shaft centre; place it on the correct body face using the manufacturer drawing/STEP.
- XM horn in the inspected sheet: eight M2 x 0.4 holes on 16 mm PCD, maximum thread depth 2.0 mm. Hole indexing and horn revision must be checked against the supplied horn; another horn drawing may have a different depth. The AX and XM horn patterns are not interchangeable.
- The front case-retaining screws, shaft-centre screw, horn attachment screws and frame attachment screws serve different functions. Do not replace them all with M3.
- Screw projection = under-head length minus printed bracket, washer and spacer stack. Check both sufficient engagement and the maximum allowed projection, with tolerance, before choosing length. A blind-hole depth is a maximum, not an instruction to bottom out. Preserve prescribed ROBOTIS spacers/idler arrangements.

## Printed fastening features
These are trial CAD values, not universal Bambu tolerances:
- M2 through-clearance: 2.3 mm; M2.5: 2.8 mm; M3: 3.4 mm. Print a coupon; holes may need finishing.
- M3 shell nut pocket: 5.8 mm across flats, 2.7 mm deep for a nominal DIN 934 M3 nut (5.5 mm AF, 2.4 mm high). Check the purchased nut. Pocket oriented with flats resisting rotation, open assembly access, positive retention via the cover.
- M3 boss outer diameter: 11 mm provisional. A 5.8 mm AF pocket is about 6.70 mm across corners, leaving about 2.15 mm minimum radial material in this boss. Add ribs and root fillets; keep pocket corners away from cutouts.
- Aim for at least 2 mm material between pocket corners and free surfaces as a starting layout constraint, not a strength guarantee. Screw-head/washer seat and bearing retention require additional local thickness.
- Keep repeated motor hole centres exact while tuning only clearances. Do not place nut pockets behind XM threaded motor-body holes.
- Use metal fasteners and nuts. Structural printed screws are not part of this design.

## Lightweight architecture
Proposed J2-J3 spacing 120 mm; J3-J4 spacing 100 mm; provisional distal wrist/tool chain 150 mm. Shoulder-to-tool horizontal reach about 370 mm. The 150 mm distal packaging must be verified using all four actual AX motor envelopes; do not shrink motors to fit the render.

Use a hollow ribbed closed box for each main link, local double-shear clevises, and small covers only where needed. Keep material away from the neutral axis; do not replace a torsionally stiff box with two unbraced decorative plates. Ventilated motor saddles and sparse cable clips replace large cosmetic motor shrouds.

Provisional print geometry for a 0.4 mm nozzle:
- Main link wall: 2.0-2.4 mm; internal ribs: 2.0 mm.
- Cosmetic removable covers: 1.2-1.6 mm.
- Bearing cheeks and bolt-bearing pads: 4-6 mm locally, subject to bore size and stress checks.
- Fillet rib/boss roots; preserve continuous material around bearing bores.
- Bambu Studio starting profile: 0.20 mm layer, about 5-6 wall loops where geometry allows, 5 top/bottom layers, 15-20% gyroid only in remaining enclosed bulk. Use local solid regions at fasteners and gear hubs. Final mass comes from sliced extrusion volume, not the infill percentage alone.
- Orient main links lengthwise on the bed with load-bearing skins continuous. Orient gear teeth in the XY plane. Check bearing-yoke layer orientation for peel/splitting; supports and surface finish remain part-specific.
- No automatic material change to carbon-filled nylon. PLA is the user's assumed baseline.

PLA sensitivity matters near warm motors: Bambu's cited PLA Basic TDS gives heat-deflection values of 54 degrees C at 1.8 MPa and 57 degrees C at 0.45 MPa. These are test results, not permissible arm service temperatures. Leave ventilation, measure bracket temperature and creep under actual duty, and do not use the servo's maximum allowable internal temperature as a PLA limit. If tests fail, revise bracket geometry/material rather than assuming the motor temperature shutdown protects PLA.

## Honest mass budget
Targets below include purchased moving hardware and wires separately. They are design allocations, not masses measured from CAD. Moving assembly above J2 is budgeted at 590.4 g without payload. Proposed moving printed parts total 145 g; all nonmotor moving parts total 290 g. Additional J2 drive hardware near the pivot, pedestal, J1 drive, turntable, base and electronics still add mass to the full robot. Do not report 590 g as total robot mass.

| Lump | Mass g | Horizontal coordinate from J2 mm |
|---|---:|---:|
| upper link print | 45.0 | 60 |
| upper link hardware | 25.0 | 60 |
| J3 XM430 | 82.0 | 120 |
| J3 reduction and support | 40.0 | 120 |
| forearm print | 35.0 | 170 |
| forearm hardware | 20.0 | 170 |
| J4 AX12 | 54.6 | 220 |
| J5 AX12 | 54.6 | 255 |
| J6 AX12 | 54.6 | 290 |
| gripper AX12 | 54.6 | 325 |
| wrist print | 40.0 | 270 |
| wrist hardware | 25.0 | 290 |
| gripper print | 25.0 | 345 |
| gripper rails and screws | 15.0 | 340 |
| moving cables | 20.0 | 190 |

## Static screening
Gravity torque: sum(mass x 9.80665 x horizontal lever arm). Shoulder at 0 mm; elbow at 120 mm; wrist pitch at 255 mm; payload at 370 mm. Only masses distal to a joint are included. Wrist printed parts are conservatively lumped distal to J5. This is one horizontal straight-arm screening pose, not the maximum over all six-axis poses.

| Payload | J2 shoulder | J3 elbow | J5 wrist pitch |
|---|---:|---:|---:|
| 0 g | 1.209 N m | 0.555 N m | 0.105 N m |
| 50 g | 1.390 N m | 0.678 N m | 0.162 N m |
| 100 g | 1.572 N m | 0.801 N m | 0.218 N m |
| 200 g | 1.935 N m | 1.046 N m | 0.331 N m |

Planning motor torque: 0.82 N m XM and 0.30 N m AX. These are estimates based on 20% of published 12 V stall torque, not independently validated continuous thermal ratings for this assembly.
Assumed external reduction efficiency: 80%. J2 4:1 -> 2.624 N m estimated output; J3 2:1 -> 1.312 N m estimated output; J5 direct -> 0.300 N m.
At 50 g: static ratios approximately 1.89, 1.94, 1.86 respectively.
At 100 g: approximately 1.67, 1.64, 1.38 respectively. Wrist pitch fails a chosen preliminary 1.5x static-reserve screen.
At 200 g: wrist pitch exceeds the estimated planning torque even before dynamics.

Therefore start commissioning unloaded, then use 50 g for slow-motion testing; 100 g remains a development goal, not a rated payload. The 1.5x screen is an engineering assumption, not a safety standard or structural factor of safety. Acceleration, gearbox losses beyond the assumed value, actual thermal behavior, off-axis loads, backlash, cable forces and printed-part strength require separate checks.

Removing 10 g at a 300 mm horizontal lever saves 0.0294 N m at the shoulder. Moving distal mass closer is more useful to shoulder torque than lightening the stationary base.

## Bearings, gears and force
No motor has a universal 'kg it can hold' rating. Output torque, radial/axial shaft load, output overhang, motor thermal duty, base overturning load and print stiffness are separate constraints.

ROBOTIS lists XM radial force 40 N (manual reference location 10 mm from horn) and axial force 20 N. These are not multi-kilogram arm payload ratings. AX shaft-load limits were not verified; do not infer them from stall torque.

Use independent output shaft bearings for J2/J3 and a moment-rated base turntable. External pinion shafts should also be bearing supported where gear force would overload motor bearings. The motor transmits torque via a suitable coupling.
Example only: 1.390 N m at a driven pitch radius of 40 mm gives about 34.8 N tangential gear force; a 20-degree pressure angle gives about 12.7 N separating force. These go into shaft/bearing/bracket calculations. Torque multiplication does not make these forces disappear.

A 1.390 N m moment reacted as a pure force couple across 40 mm bearing spacing corresponds to about 34.8 N per couple force, before additional weight and gear loads. This example illustrates the need for bearing spacing; it is not a bearing selection.

J1 remains AX with proposed external 3:1 gear reduction: at most 100 degrees total output travel from 300-degree joint mode, before margins. The bearing reduces rotation resistance and carries weight/moment; the gear adds reduction and friction. Check yaw acceleration and gear tooth load separately.
Gripper pinion must engage two opposed racks, with rails taking jaw moments. Force at the pads depends on pinion radius, efficiency, current/torque limit and object friction; no grip-force rating is released.

## Release gates
1. Match actual horns, manufacturer mounting coordinates and screw protrusion with a small PLA fit coupon.
2. Resolve six-axis motor packaging and collisions in dimensional CAD, including cable bends and tools for assembly.
3. Weigh sliced/printed parts and hardware; replace every budget mass and centre of gravity.
4. Check full-pose gravity loads, acceleration, pinion/bearing forces and print-layer load directions.
5. Bench-test brackets and gears; log servo and PLA bracket temperatures, deflection, backlash and creep. Increase payload only from evidence.

## Sources
- AX official dimensions: https://emanual.robotis.com/assets/images/dxl/ax/ax-12a_dimension.png
- AX manual: https://emanual.robotis.com/docs/en/dxl/ax/ax-12a/
- ROBOTIS XM datasheet: https://media.distrelec.com/Web/Downloads/_t/ds/Dynamixel_XM-Series_eng_tds.pdf
- XM manual: https://emanual.robotis.com/docs/en/dxl/x/xm430-w350/
- XM torque/load estimates: https://robotis.us/products/dynamixel-xm430-w350-t
- Bambu PLA Basic TDS: https://store.bblcdn.com/s7/default/b189de92249a4b9ebed28b8ea1f080f0/Bambu_PLA_Basic_Technical_Data_Sheet.pdf
- Example M3 DIN 934 nut: https://www.accu.co.uk/hexagon-nuts/766485-NUT930M3C

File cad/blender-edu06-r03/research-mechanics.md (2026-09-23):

# R03 independent mechanical feasibility review

Date: 2026-09-23. This is an engineering planning study, not a load rating or a manufacturing release. The numerical mass and centre-of-mass assumptions below must be replaced with the generated model's measured volumes and actual printed-part weights.

**Revision note:** the first independent Blender audit found considerably more mass than the budgets in this document and excessive elbow demand. The builder is being revised to a **3:1 elbow reduction (20/60 teeth, module 1.25, 50 mm centres)** and lighter wrist parts. The 2:1 elbow figures below are retained as the original planning study, not as the final model specification. Use `gear-pairs.json` and the independently generated `mass-load-audit.json` for the actual delivered geometry and motor-demand screening. No provisional payload in this planning document overrides a failed as-modelled load audit.

## Architecture that preserves the reference image

The reference has a green open-front box, cream gears and joint discs, ribbed green links, black motors, visible cable loops, and two gear-driven pivoting fingers. These features can be retained. Its apparently coaxial shoulder/elbow motor layout cannot simultaneously provide an external reduction: a real reduction needs an offset motor shaft, a separate output shaft, and gears that actually mesh. The three wrist axes plus gripper require four physical AX-12A motors, not two decorative motors or scaled-down cases.

Use six revolute arm axes (J1 yaw, J2 shoulder pitch, J3 elbow pitch, J4 forearm roll, J5 wrist pitch, J6 tool roll) and a seventh motor for the fingers. Only printed components, motor assemblies, electronics, cables, screws and nuts are assumed available. No purchased bearings, steel axles, metal brackets, threaded inserts, springs, belts, or rubber pads are assumed.

Recommended starting lengths are 100 mm shoulder-to-elbow and 85 mm elbow-to-wrist-roll. The wrist/gripper remains about 170 mm long because real AX cases occupy space. The provisional horizontal shoulder-to-contact distance is 355 mm. Shortening the links alone will not eliminate the distal four-motor mass.

| Drive | Teeth | Module | Pitch centres | Face width | Large gear outside diameter |
|---|---:|---:|---:|---:|---:|
| J1 yaw, 3:1 | 20 / 60 | 1.5 mm | 60 mm | 10 mm | 93 mm |
| J2 shoulder, 4:1 | 20 / 80 | 1.25 mm | 62.5 mm | 12 mm | 102.5 mm |
| J3 elbow, 2:1 | 20 / 40 | 1.5 mm | 45 mm | 10 mm | 63 mm |
| Opposed gripper jaws, 1:1 | 20 / 20 | 1.5 mm | 30 mm | 7 mm | 33 mm |

These are external 20-degree involute gears. Nominal centres are m(z1+z2)/2; outside diameter is m(z+2). Tooth thickness needs an explicit tangential backlash allowance, initially 0.20-0.30 mm total at the mesh, then adjustment from printed coupons. Gear roots, face widths, and spoke openings need strength assessment; a mesh that animates is not proof against tooth failure. Print each gear flat with its rotation axis normal to the bed. Do not substitute sawtooth circles or simple sinusoidal teeth.

J1's AX is fixed inside an approximately 220 x 180 x 90 mm open-front box. Its pinion shaft and the output turntable shaft each need printed support journals independent of the servo horn. Allow straight screwdriver access, space to connect cables, and a removable top deck. Put U2D2 in a small fixed tray, away from the gears and swept wire loops. A U2D2 is an interface, not the motor power supply.

J2's XM stays on the yaw platform and drives an offset shoulder pivot. J3's XM is carried by the upper link and drives an offset elbow pivot. Their larger output gears and gear covers can be styled as the cream discs in the reference. Cover the gear teeth while providing removable access.

## Printed support strategy

- Base: printed hollow yaw spindle, nominal journal diameter 32 mm, two replaceable printed sleeves each 14 mm long, centres separated approximately 45 mm. A 16 mm cable bore is a starting envelope, subject to actual connector passage. Use a broad replaceable printed thrust ring, approximately 60 mm ID and 100 mm OD. Keep a separate retaining collar above the thrust surface.
- Shoulder: printed output journal diameter 24 mm, supported in both clevis cheeks by approximately 12 mm-long sleeves separated at least 40 mm. Elbow: 20 mm journal with two sleeves. Avoid cantilevering the complete arm from an AX/XM horn or one thin printed side plate.
- Motor pinions need a supported printed journal/coupler, with an axial clearance to the motor case. Motor horns transmit torque; they should not be the only path for the external arm's bending moment.
- Bushings are plain sliding interfaces. Printed plastic is not automatically low-friction. Baseline dry friction, wear and backlash are unknown; use slow intermittent demonstrations until measured. Use replaceable sleeves and thrust rings so worn parts can be reprinted.
- Start with 0.25 mm radial clearance (0.50 mm diametral) for printed sleeves and 0.3-0.5 mm axial clearance. These are coupon-test values, not universal printer tolerances. An interference-fit sleeve can distort its bore.
- Retaining screws/nuts must bottom against a shoulder or printed spacer, leaving the running clearance. Tightening a nut directly against two moving cheeks will lock the joint. Printed spacer creep can gradually loosen retention; access for inspection is necessary.
- Use closed or ribbed box links and generous fillets at the motor/yoke transitions. A useful first shell thickness is 2.4-3.2 mm; highly loaded cheeks and bolt bosses start around 5-6 mm, with ribs. These are geometry starting points, not validated strength dimensions. Excessive solid fill at the wrist worsens every upstream moment.

For scale, the 50 g case below gives a 1.233 Nm shoulder gravity moment. If a base pair of journal sleeves is separated by 45 mm, its moment reaction is approximately M/L = 27.4 N at each support, before dynamics. On a 32 x 14 mm projected journal area this is about 0.061 MPa mean bearing pressure. This low average does not establish PLA creep life, local contact pressure, layer strength, or friction.

## Fasteners and motor envelopes

Published motor envelopes are AX-12A 32 x 50 x 40 mm and XM430-W350 28.5 x 46.5 x 34 mm. Keep motors at these dimensions and put fit clearance in their mounts. Allow cable connectors, bend radii, horn thickness, central screw access, and the full swept volume of case corners. Do not infer mounting-hole positions from a photorealistic concept image.

Starting printed through-hole diameters: M2 2.3 mm, M2.5 2.8 mm, M3 3.4 mm. M3 nut pockets can start at 5.8 mm across flats and 2.7 mm depth for a nominal 5.5 mm x 2.4 mm nut. Print a fit coupon first. Captive pockets need an insertion opening and an anti-rotation wall. Keep adequate material around each pocket rather than letting a hex corner break through a rib.

The manufacturer horn patterns and maximum screw engagement must be checked against the exact motor/horn revision. M2 horn screws are not interchangeable with M2.5 case screws, and printed-clearance assumptions are not evidence of motor-thread depth. No long bolt may bottom in a motor hole. Through-bolted printed case cradles are possible, but must not clamp covers or block cooling/connector access. The precise purchased screw inventory is still unknown.

## Gravity moment calculation

Use g = 9.81 m/s^2. The table assumes the links and wrist are extended horizontally. x is the centre of mass measured from J2, J3 is at x=100 mm, and J5 is at x=230 mm. This is deliberately transparent: the masses below are budgets, not extracted from the proposed Blender model.

| Moving item | Mass budget | x from J2 | J2 moment | J3 moment |
|---|---:|---:|---:|---:|
| Upper-link printed shell | 40 g | 50 mm | 0.0196 Nm | 0 |
| J3 motor + elbow mount/reduction | 122 g | 100 mm | 0.1197 Nm | 0 |
| Forearm shell | 30 g | 142.5 mm | 0.0419 Nm | 0.0125 Nm |
| J4 AX + frame | 79.6 g | 190 mm | 0.1484 Nm | 0.0703 Nm |
| J5 AX + frame | 79.6 g | 230 mm | 0.1796 Nm | 0.1015 Nm |
| J6 AX + frame | 74.6 g | 270 mm | 0.1976 Nm | 0.1244 Nm |
| Gripper AX + jaws/gears/frame | 99.6 g | 315 mm | 0.3078 Nm | 0.2101 Nm |
| Moving cables + fasteners | 25 g | 180 mm | 0.0441 Nm | 0.0196 Nm |

For every distal item, tau_j = g * sum(m_i * horizontal_distance_i). Fixed shoulder-motor and base mass do not contribute to J2 torque but do affect base loading. The table approximates J3's mass at its pivot; actual motor-offset COM must be included in the final calculation.

| Assumed payload at x=355 mm | Total moving mass | J2 gravity | J3 gravity | J5 gravity |
|---|---:|---:|---:|---:|
| 25 g | 575.4 g | 1.146 Nm | 0.601 Nm | 0.143 Nm |
| 50 g | 600.4 g | 1.233 Nm | 0.663 Nm | 0.174 Nm |

The four distal AX motors alone weigh 218.4 g. Three wrist motors plus the gripper must not be omitted from the load calculation. A visually slim wrist cannot be obtained by shrinking those case meshes.

For preliminary sensitivity only, assume combined gear/journal efficiency eta=0.65 and an allowance factor of 1.5 on the gravity torque. Motor estimate is tau_motor = 1.5*tau_joint/(ratio*eta). The factor is not a measured dynamic simulation or an established safety factor for printed material.

| Payload | J2 motor, 4:1 | J3 motor, 2:1 | J5 direct, factor 1.5 |
|---|---:|---:|---:|
| 25 g | 0.661 Nm | 0.693 Nm | 0.214 Nm |
| 50 g | 0.711 Nm | 0.766 Nm | 0.260 Nm |

At 12 V, published stall torques are 1.5 Nm for AX and 4.1 Nm for XM430-W350. AX documentation recommends loads at or below one fifth stall for stable motion. ROBOTIS lists 0.82 Nm as an estimated continuous torque for XM, explicitly derived as 20% of stall. Thus 0.30/0.82 Nm are planning comparisons, not guarantees for this printed assembly. Direct J2 drive exceeds the XM planning comparison even before the allowance; do not claim it can hold the horizontal model continuously. At eta=0.50, the same 50 g case and factor give 0.925 Nm at J2 and 0.995 Nm at J3: both exceed 0.82 Nm. This illustrates why actual friction and temperature measurements are essential.

J4/J6 roll torques depend on transverse COM, not the total forward reach. Keep all downstream components centred on the roll axis. For example, a 303.4 g distal group displaced 35 mm transversely would produce approximately 0.104 Nm at J4 before friction and acceleration. Derive this from the final model, not from a presumed perfect balance.

The gear-jaw gripper has mirrored pivots, not a parallel-jaw trajectory. If both 65 mm moment arms share motor torque equally, lifting 50 g by friction alone with a hypothetical friction coefficient 0.25 requires about 0.128 Nm before transmission losses. Actual hard PLA contact friction is unknown. Use small cupped fingers for geometric retention and test light objects; do not label an arbitrary object a validated payload. AX torque-limit register values are not calibrated jaw-force measurements.

## Movement, stability and print checks required before release

1. Export each printable part as a separate closed, consistently oriented mesh in millimetres; check manifold edges, thickness and connected components. Motor/electronic reference meshes must never enter the print set.
2. A1 nominal build volume is 256 mm per side. Verify every oriented part's bounds, including a margin for brim and printer exclusions, rather than assuming the complete assembly is printable in one piece.
3. Use actual mating holes and nut pockets. Check nominal coaxiality, slot insertion, tool access and screw stack length numerically. Check clearances after printing coupons.
4. Parent each body to its actual joint frame. Gear relationships are theta_out = -theta_motor/N, with correct initial tooth phase. Paired gripper gears rotate equally and oppositely. A kinematic driver is not a force or friction solver.
5. Sweep joint ranges and sample combined poses. Check gear and bushing contacts separately from forbidden body collisions; contact intended for meshing must not be misreported as an assembly clash. Check cables manually in extreme poses.
6. With J1 3:1 and an AX positional span of 300 degrees, theoretical yaw travel is only 100 degrees. An initial software range of +/-45 degrees leaves some margin. More reduction also reduces output speed and usable positional range. J2 4:1 should use a deliberately limited output arc with the corresponding motor range/mode accounted for.
7. Prevent tipping. A free-standing 220 mm box is not automatically stable against a 1.23 Nm arm moment. At a 100 mm support half-width, even a simplified 1.5 Nm resisting target requires about 1.53 kg effective weight behind the tipping edge. Use printed table-edge clamps with the user's screws/nuts or a positively screwed-down mount; do not hide an unspecified metal ballast in the base.
8. Initial test is unloaded, slow, and short. Measure base breakaway torque, backlash, printed-journal heating, servo temperature and actual printed masses. Recalculate moments for the as-built masses, then test 25 g before considering 50 g. Stop before any servo/PLA thermal or deformation limit.

## Primary references checked

- [ROBOTIS AX-12A manual](https://emanual.robotis.com/docs/en/dxl/ax/ax-12a/): published motor dimensions, mass, voltage/position range, stall torque, and one-fifth-stall design guidance.
- [ROBOTIS XM430-W350-T specification](https://robotis.us/products/dynamixel-xm430-w350-t): motor dimensions, 82 g mass, 4.1 Nm stall, and the explicitly estimated 0.82 Nm continuous value. The manufacturer's radial/axial load limits apply to its output, not to a guaranteed tip payload for this arm.
- [ROBOTIS XM430-W350-T engineering specification](https://www.robotis.com/shop/item.php?it_id=902-0124-000): available operating modes, dimensions and rated-voltage data; continuous-operation fields are unfilled.
- [ROBOTIS U2D2 manual](https://emanual.robotis.com/docs/en/parts/interface/u2d2/): interface layout and separate motor power requirement; confirm connector revision against the user's unit.

Conclusion: a compact low-payload educational prototype is mechanically plausible with actual external J2/J3 reductions, independently supported printed pivots, a secured base and measured fit/friction. This study does not certify that a visual model, an animation or the untested printed assembly works under load.

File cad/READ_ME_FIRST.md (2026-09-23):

# EDU-05 — Blender arm concept

This is an editable concept with separate structural meshes. The motor types and dimensions, payload, reach, printer, bearings, fasteners and transmissions have not been specified. The supplied STLs are **prototype geometry for inspection and fit trials**, not a validated functional robot kit.

## Open the model

Open `EDU05_robot_arm_concept.blend` in Blender. The scene selector offers:

- **EDU-05 | Assembled** — the posed arm, reference motors and labeled joints.
- **EDU-05 | Parts layout** — all 13 unique prototype parts, with names, quantities and bounding dimensions.

In the Outliner, expand **03 | Joint controls — rotate these empties**. Select a JOINT object and rotate around the local axis in its name. J1 uses local Z, J2/J3/J4 use local Y, and J5 uses local X. The downstream parts follow the joint. The initial pitch angles use the negative local Y direction. The joint labels are presentation annotations for the saved pose; their leader lines do not track subsequent edits.

The embedded text blocks include the generator, parameters and a short introduction. The scene uses millimetres: one Blender coordinate unit equals one millimetre. The native file preserves the separate parts and the parent hierarchy.

## What is included

| ID | Structural part | Assembly quantity |
|---|---|---:|
| P01 | Base plate | 1 |
| P02 | Motor housing | 1 |
| P03 | Rotating deck | 1 |
| P04 | Shoulder bracket | 2 |
| P05 | Upper link side plate | 2 |
| P06 | Forearm side plate | 2 |
| P07 | Upper link spacer | 2 |
| P08 | Forearm spacer | 2 |
| P09 | Wrist side plate | 2 |
| P10 | Roll carrier | 1 |
| P11 | Gripper palm | 1 |
| P12 | Gripper finger | 2 |
| P13 | Clearance coupon | 1 optional test piece |

Motors, shafts, bearings and guide rods are in the **reference hardware** collection. They are excluded from STL export and are not a purchasing specification. The base coupling, joint drive interfaces, gripper actuation and hardware retention still need detailed design. The model is not collision-checked or load-tested.

## Prototype STL files

Each file in `prototype_stl/` contains one part, centered in X/Y and resting at Z = 0. STL has no unit metadata; import these at **millimetres, 100% scale**. The base diameter should measure 180 mm. The upper link has 180 mm between pivots and is 226 mm overall, so it will not fit flat on a 220 mm bed without reorientation or a design change.

The automated mesh checks require one connected shell, no non-manifold edges and positive enclosed volume for each exported part. These checks establish closed geometry, not hardware compatibility, mechanical strength, dimensional accuracy of the printer, or support-free printability.

Start with **P13_clearance_coupon.stl** after checking its dimensions in your slicer. The holes from left to right in the parts layout are 3.4, 4.4, 8.4 and 6.6 mm. Decide filament, wall counts, infill, print orientation and supports after the expected joint loads and printer are known; no final structural print settings have been assumed.

## Edit and regenerate

Edit `parameters.json` and regenerate using a separate Blender process:

```text
blender --background --python build_robot.py
```

Run this from this directory or use absolute paths. The script writes its output next to itself. It creates new scenes without deleting existing scenes, but overwrites this concept's output files when rerun. Retain a copy before keeping manual edits to the generated model. Some mounting geometry remains explicit in `build_robot.py` and is intentionally provisional.

## Next measurements

To turn this into an assembly-ready design, provide the model and dimensions of every motor, mounting hole spacing, output shaft or servo horn geometry, intended bearings, reach, payload, and printer build volume. Then revise the transmission, joint stack dimensions, fastener lengths, mechanical stops and clearances, and test a single joint before printing the complete arm.

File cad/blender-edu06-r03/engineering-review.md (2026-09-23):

# EDU06 R03 — engineering review

No physical prototype has been assembled or loaded. This release is an editable, dimensioned engineering prototype, with prototype STL exports. It is not a certified payload rating or a production release.

The Blender scene is the actual manufacturing geometry and kinematic assembly. Its green/ivory appearance follows the concept image. Motor cases, gear centres, printed plain bearings, nut pockets, rear-access screw stacks and link lengths determine the geometry; they are not traced from an AI image. All fabricated structure, gears, bushings, journals and spacers are printed. Purchased motors retain their supplied hardware; additional fastening hardware is nuts and screws.

## Completed digital checks

| Check | Recorded result | Scope |
|---|---|---|
| Exported STL geometry | 179/179 passed; 0 failed; 0 review | Nondegenerate triangles, closed consistently directed edges, positive volume, connected surface, grounded and within a 256 mm cube |
| Exact gear-profile samples | 244 samples across four pairs; PASS | 61 phases over each pinion tooth pitch, polygon penetration checks and deliberately wrong-phase negative control |
| Joint/control responses | 7 controls × 3 values; all passed = True | Evaluated output angles, pinion ratios, end-effector pose and jaw opening |
| Assembly pose samples | 18 poses, including an explicitly out-of-range horizontal stress case | Mesh intersection/containment screening at selected poses, not continuous collision proof |
| Physical validation | Not performed | Print fit, strength, friction, creep, heat, durability and powered operation remain unmeasured |

Audit details and limitations are retained in `stl-audit.json`, `gear-profile-audit.json` and `mass-load-audit.json`. STL topology checks do not test every possible triangle self-intersection or establish minimum wall strength. Collision screening excludes same-body mating parts, fasteners and visual cables; the manual fastener-stack review is separate.

The saved animation was also checked at **31 actual timeline snapshots**. Unresolved crossings/penetrations: **0**; joint-limit violations: **0**. See `demo-trajectory-audit.json`. This is discrete sampling, not a continuous swept-volume proof.

## Dimensions and moving interfaces

| Feature | Nominal geometry in mm |
|---|---|
| Base | 240 × 190 nominal floor; 241 × 190 actual case envelope including tab ends; 5 floor; 4 walls; lid top 95; printed feet 8 |
| AX-12A envelope / purchased mass | 32 × 50 × 40 / 54.6 g |
| XM430-W350-T case / purchased mass | 28.5 × 46.5 × 34 / 82 g; installed horn datum detailed in motor guide |
| U2D2 envelope | 48 × 18 × 14.9; tray centred at(-61,-64), above the base floor |
| Yaw | 20/60 teeth, module 1.5, centre distance 60, 10 face width |
| Shoulder | 20/80 teeth, module 1.25, centre distance 62.5, 12 face width |
| Elbow | 20/60 teeth, module 1.25, centre distance 50, 10 face width |
| Gripper | 20/20 teeth, module 1.5, centre distance 30, 6 face width; pivoting jaws |
| Gear profile | 20° involute working flanks; nominal total tangential backlash 0.20; relieved radial roots, no tooth-fatigue validation |
| Upper arm | 100 pivot spacing; hollow printed corner rails |
| Forearm | 85 nominal beam length plus integral roll-motor bulkhead; see actual joint datums for complete reach |
| Main yaw journal | Ø32 printed shaft, Ø32.5 running bore; two separated sleeves and printed thrust ring |
| Shoulder / elbow journals | Ø24 / Ø20 shafts, Ø24.5 / Ø20.5 bores; printed retainers leave axial clearance |
| Pinion journals | Ø8 / Ø8.5 running fits |
| General M3 clearance / nut | Ø3.4 / 5.8 across-flats pocket; side-loading entrances6.4 where used |

AX and XM horn patterns use Ø16 pitch circles with four/eight M2 holes respectively. AX pinion/gripper M2×6 through 4 mm floors gives2 mm engagement; XM M2×6 through 4.5 mm gives1.5 mm. Raised wrist adapters use AX M2×10 through 7 mm, giving 3 mm engagement. Compare the supplied horn revision, actual screw length and printed thickness before fastening. Manufacturer datum drawings, mounting stacks and assembly sequence are in `motor-and-fastener-guide.md` and `motor-interface-schedule.json`.

The elbow's front/rear supports are tied with four 38 mm printed spacers and shared M3×70 bolts. Central pivot-retaining bolts load rotating shafts/caps rather than clamping stationary bearing cheeks. The gripper idler uses a stationary compression sleeve so tightening its bolt does not lock the rotating jaw. Base-lid and deck-flange nuts have side-loading pockets with material above them to carry screw tension. The base uses sliding polymer bearings: gears provide reduction, but do not eliminate bearing friction.

## Gravity and motor-torque screening

The selected planning payload is **25 g**, pending the user's intended object weight. It is a calculation input, not an approved operating payload. Five AX motors plus two XM motors alone weigh 437 g; distal AX motors make the wrist mass significant.

Printed mass is integrated from the closed CAD volumes at PLA 1.24 g/cm³, assuming solid material. Actual sliced mass depends on walls, infill and supports. A 10% allowance is added to moving mass for fasteners and wiring. Motor centres of mass use the external reference envelopes. Gravity calculations use:

`joint torque = axis · Σ[(centre of mass − joint origin) × mass × gravity]`

`estimated motor torque = |joint torque| / (gear ratio × assumed efficiency)`

Total printed solid mass: **2474 g**. Moving mass before/after the 10% allowance: **1817 / 1999 g**. These are CAD estimates, not weighed parts.

The following are motor-shaft torques in N·m with 25 g at the fingertips. Maxima use only the sampled poses inside the declared limits. The 1.5 column is an illustrative extra allowance, not a dynamics simulation.

| Joint | Ratio | Home gravity | Sampled maximum | Maximum ×1.5 | Planning comparison |
|---|---:|---:|---:|---:|---:|
| J2 | 4:1 | 0.635 | 0.751 | 1.127 | 0.82 |
| J3 | 3:1 | 0.649 | 0.665 | 0.997 | 0.82 |
| J4 | 1:1 | 0.087 | 0.204 | 0.306 | 0.30 |
| J5 | 1:1 | 0.202 | 0.225 | 0.337 | 0.30 |
| J6 | 1:1 | 0.003 | 0.046 | 0.068 | 0.30 |

The comparisons 0.30 N·m AX /0.82 N·m XM are 20% of published stall values. They are **not manufacturer continuous-duty guarantees**. See the JSON for assumed gear efficiencies. There are **0** sampled gravity cases above these comparisons across the 0 / 25 / 50 g load cases within the declared limits. J1 is excluded from the motor-gravity table because its axis is vertical. Zero gravity torque at yaw does not mean zero required torque: breakaway friction, acceleration and cable forces are absent from that value. Full bending moments on the joint bearings are also recorded separately; motor-axis torque alone cannot validate those bearings.

The illustrative 1.5× allowance exceeds the planning comparisons at several joints, including shoulder and elbow. The 50 g static shoulder case has only about 4% margin. Retain 25 g as a provisional fit/load-testing target; no operational payload is assigned. The 25 g static centre-of-mass projection remains at least 37.46 mm inside the foot-centre support polygon in the sampled poses. This does not replace bench attachment or dynamic tipping checks.

## Motion limits and remaining checks

Declared control ranges are J1 −40…40°, J2 45…85°, J3 30…75°, J4 −50…50°, J5 −30…30°, J6 −50…50°, GRIP 0…24°. These are modeled ranges, not verified servo calibration values. Rotation signs and horn assembly zeros must be mapped to physical servo IDs before any powered test. There is no motor-control script in this release.

Pose names with sampled gross interpenetration: **none**. Poses flagged for crossing/contact review: **none**. Contact classifications and sampled penetration points are preserved for inspection; intended contacts are not silently reported as a universal clearance pass. The rigid-body animation is not a friction/contact simulation.

Before printing the full arm, print the hole/nut coupon, both horn coupons, one cradle/shim set and a shaft/bushing pair. Confirm material identity and measure actual parts with calipers. The 0.20 mm spacers and0.30 mm shims require suitable layer settings and measurement. STL orientation is an initial export orientation; inspect supports, bridging, layer direction and small-feature resolution in Bambu Studio. A 1 volume fit excludes brim and plate restrictions.

Before assigning a payload, measure breakaway/running torque of the printed bearings, check gear tooth/root strength and backlash, measure joint deflection, establish stable mounting, and perform supported low-speed thermal/load tests. PLA creep, friction and layer strength are not solved by mesh checks. Wrist AX horns still transmit wrist bending loads; allowable radial/axial loads and printed-carrier stiffness need verification. There is no finite-element analysis, full cable-flex simulation, fatigue test or load certification in this release. Visual cable curves reserve routes but do not replace real service-loop fitting. U2D2 is the communication adapter; motor power requires its own appropriate supply and distribution.

## Primary references

- [ROBOTIS AX-12A](https://emanual.robotis.com/docs/en/dxl/ax/ax-12a/)
- [ROBOTIS XM430-W350](https://emanual.robotis.com/docs/en/dxl/x/xm430-w350/)
- [ROBOTIS U2D2](https://emanual.robotis.com/docs/en/parts/interface/u2d2/)
- Manufacturer drawing extracts and datum research: `research-motors.md`.

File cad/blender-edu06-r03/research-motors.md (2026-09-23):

# EDU06 R03 motor-interface research

Checked 23 September 2026. These are manufacturer reference dimensions, not measurements of the user's individual hardware. Existing L01 mass/load calculations do not validate a new geometry.

## Motor envelope and datum

| Item | Published W x H x D (mm) | Mass | 12 V stall torque | Position range |
|---|---:|---:|---:|---|
| AX-12A | 32 x 50 x 40 | 54.6 g | 1.5 N m | 0–300 degrees in position mode |
| XM430-W350-T | 28.5 x 46.5 x 34 | 82 g | 4.1 N m | 0–360 degrees; extended position mode also available |

Sources: [AX eManual](https://emanual.robotis.com/docs/en/dxl/ax/ax-12a/), [XM eManual](https://emanual.robotis.com/docs/en/dxl/x/xm430-w350/).

AX output axis is 11.5 mm below the top edge in the official front drawing. Its side drawing has a 32 mm main body depth within the overall 40 mm dimension; horn and rear projections must be represented separately. XM output axis is 11.25 mm below the top. Its drawing shows horn projections separately from the 34 mm case depth. Do not put either motor axis at the centre of its height, shrink a motor to improve a render, or treat a specification envelope as a complete installation clearance.

Sources: [official AX drawing](https://emanual.robotis.com/assets/images/dxl/ax/ax-12a_dimension.png), [ROBOTIS-authored XM datasheet, distributor mirror](https://media.distrelec.com/Web/Downloads/_t/ds/Dynamixel_XM-Series_eng_tds.pdf). Local copies: `design-concepts/motor-references/ax-12a-dimensions.png`, `xm-drawing-review.png`, and `robotis-xm-datasheet.pdf`.

## Horn interfaces

- AX: four M2 tapped holes on a 16 mm pitch circle, cardinal spacing, drawing depth 4.0 mm. Hole centres relative to output axis: (+8,0), (0,+8), (-8,0), (0,-8) mm.
- XM HN12-N101 in the inspected drawing: eight M2 x 0.4 holes, 16 mm PCD, 45-degree spacing, maximum threaded depth 2.0 mm. Check the supplied horn revision and indexing with a coupon.
- XM body-side pattern in the inspected sheet is 12 x 24 mm, M2.5 x 0.45, maximum depth 3 mm. The pattern centre is not the output axis. Use a mechanically keyed cradle if the global interface datum is unresolved.
- Preserve the manufacturer's installed horn, centre screw and thrust washer. They are supplied motor components. The printed adapter attaches to the horn holes; it does not replace the motor spline.

Screw penetration equals under-head length minus the actual bracket/spacer/washer stack. A 4 mm AX adapter and M2x6 screw gives 2 mm nominal penetration. A 4.5 mm XM adapter and M2x6 screw gives 1.5 mm nominal penetration. These are design examples; verify actual stack and tolerances before assembly, leaving clearance from the blind-hole bottom. Preserve access to the central horn-retaining screw.

## Torque and mass implications

The seven motors total 437 g. J4/J5/J6 plus the gripper motor alone total 218.4 g. Wrist compactness is constrained by four real 32 x 50 x 40 mm AX envelopes.

ROBOTIS America's [AX bulk product page](https://robotis.us/products/dynamixel-ax-12a-6pcs-bulk) and [XM product page](https://robotis.us/products/dynamixel-xm430-w350-t) identify 0.30 N m and 0.82 N m respectively as estimated continuous torque values calculated at 20% of stall. These are screening assumptions, not independently measured continuous torque for this PLA assembly. The single AX product page currently contains an inconsistent 0.2 N m stall entry; the eManual and bulk page agree on 1.5 N m, which is used here.

XM eManual gives radial load 40 N at 10 mm from the horn and axial load 20 N. These do not specify payload at the robot tool. No AX shaft-load limit was verified. Printed journals and supports must react arm moments instead of assuming unlimited motor-bearing capacity. Extra gear reduction multiplies available output torque but adds friction, backlash and gear forces. AX 3:1 external reduction permits only 100 degrees total output travel from its 300-degree position range, before end margins.

## U2D2 and wiring

[ROBOTIS U2D2 manual](https://emanual.robotis.com/docs/en/parts/interface/u2d2/): case 48 x 18 x 14.9 mm, 9 g. It is a small USB communication converter, not a motor or a motor power supply. Include a separate power entry and preserve cable access. USB changed from Micro-B to Type-C in August 2025, so an open-ended cradle/cable opening should allow either. A keyed tray and removable printed strap avoid relying on unverified mounting-hole coordinates.

AX uses TTL Protocol 1.0; XM-T is TTL and normally Protocol 2.0 (Protocol 1.0 configurable on supported firmware). Plan matched connector cables, unique IDs and a compatible control scheme; do not imply the Blender rig drives real hardware.

## Printing-specific implementation assumptions

Recommended starting CAD trial clearances, not manufacturer specifications: 0.3–0.4 mm per cradle side; M2 clearance 2.3 mm, M2.5 clearance 2.8 mm, M3 clearance 3.4 mm. Change clearance diameters after a fit coupon, never the manufacturer hole-centre spacing. All added shafts, journals, thrust pads, gears and structural components must be printed for this user's materials constraint. Printed sliding bearings need friction/wear/creep tests; a motion animation cannot validate them. Do not add purchased metal bearings or rods to the BOM.

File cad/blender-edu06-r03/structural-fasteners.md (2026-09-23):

# R03 structural fasteners — source review

Reviewed against `build_edu06.py` after the side-loaded lid/deck nuts, elbow cheek ties and U2D2 tray translation to **(−61,−64)** were added. This schedule excludes motor-cradle bolts and M2 horn screws; those are in `motor-and-fastener-guide.md`. It records the modeled mounting geometry, not a tightening-torque or strength qualification.

Unless stated otherwise, M3 clearance holes are **Ø3.4 mm**, M4 clearance holes **Ø4.5 mm**, M3 nuts **5.5 AF × 2.4 mm**, and M4 nuts **7 AF × 3.2 mm**. Circular patterns below state their **diameter**, although the generator's `pcd()` argument is a radius. Coordinates are in the named assembly's local frame.

## Modeled fastening sets

| Mount | Screw and nut quantity | Pattern and actual stack |
|---|---|---|
| B02 lid → B01 posts | 5 × M3×12; 5 M3 nuts | XY (±110,±85), plus (0,85). Head Z95; tip83. Side-loaded pockets Z85.2–88.0 have 2 mm roofs; nuts Z85.4–87.8. |
| B03 service panel → four B01 tabs | 4 × M3×16; 4 M3 nuts | Installed panel at Y−93.5, Z+5; X±103, assembled Z10/73. Head Y−95, shaft +Y, tip−79. Nuts occupy Y−84.6 to−82.2 inside rear-open tab pockets. Panel is displayed removed, with its screws following it. |
| B05 lower journal stand → floor | 4 × M3×55; 4 M3 nuts | Stand-centred 52×48 rectangular pattern, global centre (−28,0). Head Z51; tip−4. Nuts Z−2.4–0 beneath the floor; 8 mm feet provide clearance. |
| B07 upper sleeve/thrust ring → lid | 4 × M3×12; 4 M3 nuts | Ø72 pattern at 45°, centre (−28,0). Head Z98; tip86. Nuts Z87.6–90 under the lid. |
| B17 split yaw retaining collar | 1 × M3×10; 1 M3 nut | Transverse Y bolt at X23/Z37.7. Head Y−4.5, tip+5.5; nut Y1.7–4.1. The clamp retains the shaft without clamping the stationary sleeve axially. |
| B09 yaw gear → B08 shaft coupling | 4 × M3×20; 4 M3 nuts | Ø50 at 45°. Includes four 0.5 mm B18 spacers. Head Z82; tip62; nuts Z62.6–65 below the gear. |
| B10 rotating deck → B08 flange | 4 × M3×12; 4 M3 nuts | Ø58 at 45°. Four 0.8 mm B19 spacers place heads at Z118.8; tips Z106.8. Radial nut slots Z106.8–109.6 leave 2.4 mm roofs; nuts Z107.0–109.4. Tips remain above the collar ending at Z106. |
| Shoulder pedestal → rotating deck | 4 × M3×25; 4 M3 nuts | X−76/+44, Y±20: **120×40** pattern. Head Z132; tip107. Nuts Z109.6–112 beneath the rotating deck. |
| B15 printed feet → floor | 4 × M4×16; 4 M4 nuts | X±108/Y±73, Ø4.5 holes. Four 3.1 mm B16 spacers place heads at Z8.1; tips−7.9. Nuts Z−7.8 to−4.6 in bottom-open 7.3 AF pockets. These screws attach the feet, not the bench. |
| B14 U2D2 tray → floor | 4 × M3×12; 4 M3 nuts | Tray centre (−61,−64); offsets (±27,±11), giving global X−88/−34 and Y−75/−53. Head Z8; tip−4. Nuts Z−2.4–0. Ø6.2 counterbores clear heads above the 3 mm tray floor. Matching floor holes are present. |
| Shoulder and elbow rotating shaft retainers | 2 × M4×60; 2 M4 nuts | One axial bolt per reducer, inserted +Z from under-head Z−29.4 through a 1.1 mm printed spacer. Tip Z30.6; front M4 nuts Z27.3–30.5. Ø4.5 cap/flange bores; the central shaft bore is Ø8. |
| Shoulder pinion support bridge → rear cheek | 2 × M3×80; 2 M3 nuts | Reducer-frame X−92.5, Y−25/+15. Head Z55.1; bridge top51.5 and 3.6 mm printed head spacers. Tip−24.9; rear nut pockets −25 to−22.2; nuts −24.8 to−22.4. |
| Elbow pinion support bridge → rear cheek | 2 × M3×75; 2 M3 nuts | Reducer-frame X−50, Y±30. Head Z50.1; bridge top49.5 and 0.6 mm printed spacers. Tip−24.9; same rear nut-pocket and nut-Z stack as shoulder. |
| Shoulder stationary cheeks → pedestal | 2 × M3×65; 2 M3 nuts | X±25/Y−58.5; head Z31, tip−34. Nuts Z−33.4 to−31. The bolt crosses both cheek seating slots and the pedestal. |
| Upper and forearm link roots → reducer wheels/output flanges | 8 × M3×25; 8 M3 nuts | Four per link, Ø36 at 45°. Both use head Z50.6, tip25.6 and output-flange nuts Z25.7–28.1. Head spacers are 1.1 mm at shoulder and 3.1 mm at elbow. |
| Elbow assembly and front cheek → upper link | 4 × M3×70; 4 M3 nuts | Ø44 at 45°, centred at the upper-link distal pivot. Each includes an 8.1 mm head spacer, 6 mm mount standoff and **38 mm stationary between-cheek tie**. In the elbow frame, head Z−45.1, tip24.9; recessed front nuts Z22.4–24.8. This set ties both stationary cheeks; it does not clamp the rotating shaft. |
| W03/W05/W07 carriers → AX output adapters | 12 × M3×12; 12 M3 nuts | Four per carrier, Ø34 at 45°. Includes 1.5 mm printed head spacers. Head Z12.5; tip0.5; nuts Z0.6–3.0 under the raised adapter flange. Separate from M2 horn screws. |
| G04 gripper bridge → G01 palm | 2 × M3×70; 2 M3 nuts | Palm-frame X−18/Y±30. Each stack includes a 57.95 mm column and 2.15 mm head spacer. Head Z19.15; tip−50.85; nuts Z−50.75 to−48.35 in rear-open palm pockets. |
| Gripper idler retaining cap/compression sleeve → palm | 1 × M3×75; 1 M3 nut | At X0/Y15. Head Z23.95; tip−51.05; nut Z−50.75 to−48.35. Stack includes 3.95 mm head spacer, 2 mm cap and 62.95 mm stationary sleeve; the sleeve carries bolt preload so the jaw can rotate. |
| B12 yaw pinion journal support → lid | 2 × M3×20; 2 M3 nuts | X32/Y±15. The 16 mm combined support/lid stack plus 1.5 mm printed head spacers gives head Z96.5 and tip76.5. Nuts Z76.6–79 seat below the support ears. |

The J4 bulkhead is now fused into the forearm mesh, so it needs no separate attachment set. J5/J6 cradle-to-yoke and gripper-palm-to-tool-carrier connections are included in the motor-cradle through-bolts; do not count them again.

W03's raised upright is 85 mm high. In the J4 frame its mounting wall spans X−54 to−50, Y−48 to22 and Z8 to93. With the J5 datum at `(−5.05,0,65)` and a +90° rotation about Y, the AX rear-cap face maps exactly onto X−50, and its four post axes map to Y−42.5/+15.5 and Z44/86. The Ø3.4 wall holes share those axes. The ventilation cut's bounding box spans Y−36 to10 and Z20.5 to79.5; it leaves at least 3.8 mm of planar material between the bore edge and the window. This is a dimensional-alignment check, not a flexural-strength result.

## Structural-only purchase subtotal

| Screw | Quantity |
|---|---:|
| M3×10 | 1 |
| M3×12 | 29 |
| M3×16 | 4 |
| M3×20 | 6 |
| M3×25 | 12 |
| M3×55 | 4 |
| M3×65 | 2 |
| M3×70 | 6 |
| M3×75 | 3 |
| M3×80 | 2 |
| M4×16 | 4 |
| M4×60 | 2 |
| M3 nuts | 69 |
| M4 nuts | 6 |

All listed washers/spacers are printed. These are nominal generator lengths: confirm purchased under-head lengths, head profiles and assembled printed stacks. `fasteners.json` contains only calls recorded through `screw_pattern`; direct `bolt()` and `nut()` calls are also included in this source-derived table, so that JSON alone is not the complete purchasing list.

## Review disposition

- **Corrected:** top-open lid/deck nut traps now have load-bearing roofs and side entries; the elbow front cheek now has four stationary ties and continuous mounting bolts; lower stand, yaw pinion support, service panel and electronics tray have explicit bolts/nuts and mating holes.
- **Corrected:** moving the tray centre to (−61,−64) separates its closest nut (−88,−75) from the foot centre (−108,−73) by 20.10 mm, exceeding the 12 mm foot radius plus the approximately 3.18 mm M3 nut corner radius.
- **Still to provide for physical use:** the feet do not anchor the robot to a bench. Choose and verify the external bench attachment before load testing; the four M4×16 foot bolts are not an anchoring specification. The U2D2 tray provides a lateral locating pocket but has no modeled top strap or positive vertical retainer.
- **Documentation consistency:** README ratios are J1=3:1, J2=4:1, J3=3:1. The motor guide's rear-inserted screw stacks match current attachment depths: base20.05, shoulder/elbow15.35, J4=6, J5/J6=4 and gripper12 mm. Neither document claims a certified payload or physical proof of operation.

This review establishes source-level mating intent and explicit fasteners. Confirm the rebuilt meshes, interference checks, nut insertion access and actual printed fits before relying on the connections.

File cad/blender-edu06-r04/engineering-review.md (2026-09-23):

# EDU06 R04 — engineering review

This is an editable, dimensioned engineering prototype for an educational arm. It has not been physically assembled, powered or load tested. The STL files describe prototype parts; no operating payload, service life, accuracy or production qualification is assigned.

The final native model passed the recorded digital geometry, control and motion-sampling checks below. Earlier debug results are not acceptance results for this release. The checks do not establish a physical operating rating.

## Architecture and actual motion

The arm has six independent joint coordinates and a separate gripper actuator: **seven motors, six arm degrees of freedom**. J1, J4, J5, J6 and the gripper use AX-12A motors; J2 and J3 use XM430-W350-T motors. The green structure, gears, bearing sleeves, journals, spacers and gripper parts are fabricated by printing. Motors retain their supplied components; additional metal hardware is screws and nuts.

| Coordinate | Function | External transmission | Model control |
|---|---|---|---|
| J1 | Base yaw | 20/60 teeth, 3:1 | Output angle in degrees |
| J2 | Shoulder pitch | 20/100 teeth, 5:1 | Output angle in degrees |
| J3 | Elbow pitch | 20/80 teeth, 4:1 | Output angle in degrees |
| J4 | Forearm roll | Direct, with printed external journal | Output angle in degrees |
| J5 | Wrist pitch | 20/60 teeth, 3:1 | Output angle in degrees |
| J6 | Tool roll | Direct, with printed external journal | Output angle in degrees |
| GRIP | Opposed parallel jaws | One 20-tooth pinion and two racks | Clear pad gap in millimetres |

The neutral wrist places the J4 roll axis, J5 pivot centre, J6 roll axis and tool centreline on one straight line. J5 is transverse to that line. Two removable side trunnions support the pitch cradle, leaving space for the tool motor between them. The J4 and J6 printed roll sleeves are 16 mm long. The gripper uses 75 mm long fingers with replaceable keyed pads, flat contact lands and a shallow V for round objects.

The base is an open service enclosure containing the yaw motor and U2D2. Its printed turntable uses separated journal surfaces and a thrust surface. Gear reduction changes the torque and travel required from the motor; it does not remove bearing friction. U2D2 provides communication, not motor power.

Motor exteriors are tessellated from manufacturer STEP geometry. Mesh appearance is not a substitute for checking the supplied motor and horn revision. Interface datums, hole patterns, screw stacks and connector access are recorded in `motor-interface-schedule.json`. `hardware-bom.json` lists the modeled hardware; `README.md` describes assembly and file use.

Configured output ranges are J1 −40…40°, J2 60…85°, J3 30…75°, J4 −40…40°, J5 −25…25° and J6 −60…60°. The gripper pad opening is 20…70 mm. The shoulder's 60° lower operating limit keeps the sampled gravity cases within the planning comparisons; it is an operating restriction, not a payload rating. AX motor travel required over these configured ranges is 240° at J1, 80° at J4, 150° at J5, 120° at J6 and approximately 95.49° at the gripper.
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

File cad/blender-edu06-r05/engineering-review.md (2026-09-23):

# EDU06 R05 — engineering review

This editable educational-arm prototype uses exactly **four AX-12A and two XM430-W350-T motors**: five arm joints and one powered gripper. It has not been physically assembled, powered or load tested. No operating payload, service life, accuracy or production qualification is assigned.

The delivered native model passed the recorded digital mesh, control, interface and motion-sampling checks below. These checks do not establish a physical operating rating.

## Architecture
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

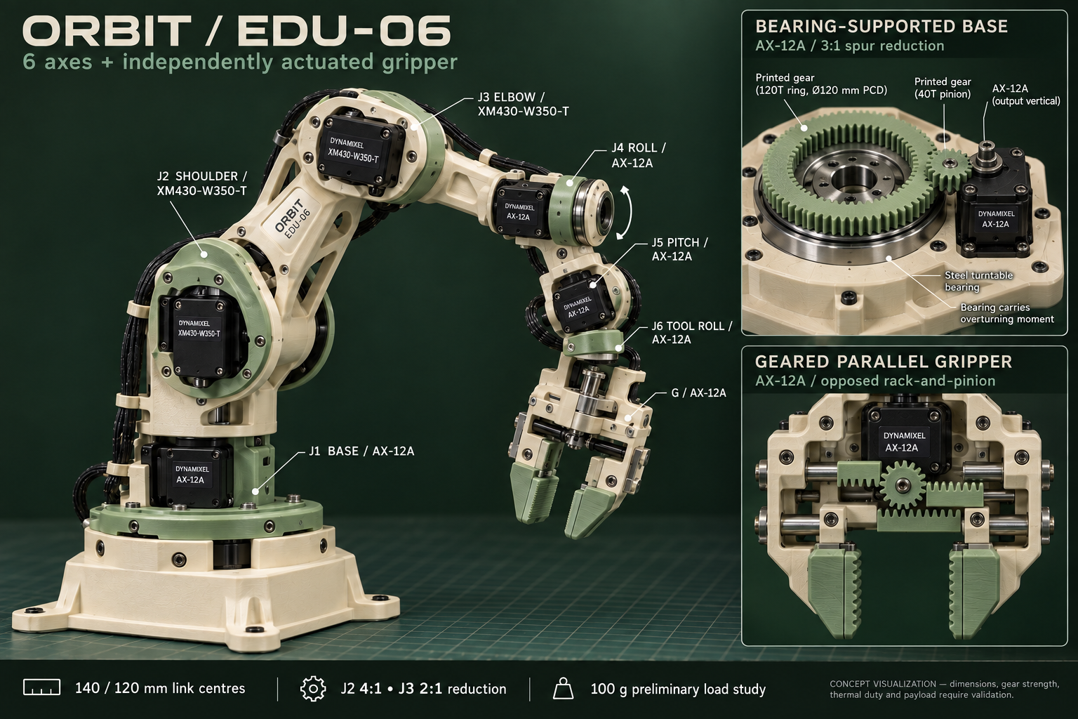
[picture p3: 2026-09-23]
design-concepts/dynamixel-edu06-concept-v1.png

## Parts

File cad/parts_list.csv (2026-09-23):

Part | Quantity | X mm | Y mm | Z mm | Description | Status
P01_base_plate | 1 | 180.0 | 180.0 | 12.0 | 180 mm base plate with four anchor holes and cable bore | Prototype — motor fit and strength unverified
P02_motor_housing | 1 | 112.0 | 112.0 | 64.0 | Open cup, 8 mm floor and 8 mm walls; provisional motor mounting | Prototype — motor fit and strength unverified
P03_rotating_deck | 1 | 112.0 | 112.0 | 10.0 | Yaw deck; coupling and bearing arrangement require hardware design | Prototype — motor fit and strength unverified
P04_shoulder_bracket | 2 | 50.0 | 64.0 | 26.0 | Reversible shoulder bracket with integral mounting foot | Prototype — motor fit and strength unverified
P05_upper_link_plate | 2 | 226.0 | 46.0 | 7.0 | 180 mm pivot spacing; two side plates form one link | Prototype — motor fit and strength unverified
P06_forearm_plate | 2 | 188.0 | 38.0 | 7.0 | 150 mm pivot spacing; two side plates form one link | Prototype — motor fit and strength unverified
P07_upper_spacer | 2 | 16.0 | 16.0 | 46.0 | Link cross spacer with through-bolt bore | Prototype — motor fit and strength unverified
P08_forearm_spacer | 2 | 16.0 | 16.0 | 30.0 | Link cross spacer with through-bolt bore | Prototype — motor fit and strength unverified
P09_wrist_side_plate | 2 | 82.0 | 38.0 | 7.0 | 52 mm wrist bridge; print two | Prototype — motor fit and strength unverified
P10_roll_carrier | 1 | 42.0 | 56.0 | 26.0 | Generic 22.4 mm bore; final bearing and motor mount unspecified | Prototype — motor fit and strength unverified
P11_gripper_palm | 1 | 76.0 | 28.0 | 12.0 | Concept parallel-gripper palm; transmission and drive not yet designed | Prototype — motor fit and strength unverified
P12_gripper_finger | 2 | 48.0 | 14.0 | 16.0 | Mirrored parallel finger; provisional rail and actuator interface | Prototype — motor fit and strength unverified
P13_clearance_coupon | 1 | 58.0 | 26.0 | 6.0 | Hole diameters left to right: 3.4, 4.4, 8.4, 6.6 mm | Prototype — motor fit and strength unverified

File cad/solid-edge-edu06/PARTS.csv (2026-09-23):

name | category | notes
C01_clearance_and_M3_nut_coupon | fit coupon | Hole row left to right: 2.2,2.3,2.4,2.7,2.8,2.9,3.3,3.4. Nut AF row:5.6,5.7,5.8,5.9. Nut pocket depth2.7.
P01_AX_horn_adapter | fit coupon | Four M2 clearance holes on16PCD. Verify screw engagement <=4mm and actual horn.
P02_XM_horn_adapter | fit coupon | Eight M2 clearance holes on16PCD. Inspected horn depth2mm maximum; verify actual horn.
P03_XM_side_mount_coupon | fit coupon | 12x24mm local pattern. NOT centred on output axis. M2.5 max3mm engagement.
P04_AX_body_mount_plate | development print | AX frame nut/bolt mounting; verify body revision and access. Output axis local0,0. Motor extends y=-11.5..38.5.
P05_base_plate | development print | 200x180x5. Anchor6.5dia,170x150pattern. 140PCD is modular plate pattern, NOT a selected turntable bearing pattern.
P06_turntable_interface_ring_PROVISIONAL | development print | Bearing unselected. This is a modular interface plate, not a raceway. Do not print for fit until bearing chosen.
P07_base_gear_60T_M2 | development print | 20degree involute, module2,60teeth; PD120; mesh80mm with20T. Backlash0.16 per gear at pitch. Root transition not strength-validated.
P08_base_pinion_20T_M2 | development print | PD40; separate shaft bearing support required; coupling/hub retention not released.
P09_shoulder_gear_80T_M1p5 | development print | 4:1 with20T,75mm centres.8.2bore requires shaft/coupling design; not a friction-fit torque connection.
P10_elbow_gear_40T_M1p5 | development print | 2:1 with20T,45mmcentres; hub/shaft retention pending.
P11_XM_pinion_20T_M1p5 | development print | PD30; independent pinion bearing support and screw access must be detailed.
P12_shoulder_bearing_cheek | development print | Trial608seat22.2dia. Gear shaft/split bearing retention pending. Not a validated shoulder housing.
P13_upper_link_cheek_120 | development print | 120mm exact pivot spacing. Requires two cheeks, four cross ties and skins. Drive flange fastening remains a release gate.
P14_forearm_cheek_100 | development print | 100mm pivot spacing; trial wrist interface not fully resolved.
P15_cross_tie_50 | development print | M3 throughbolt and two end washers; no printed structural thread.
P16_upper_box_skin | development print | Skin closure fastening must be detailed; current placement is development geometry.
P17_forearm_box_skin | development print | Development closure panel.
R03_608_bearing_REFERENCE | purchased reference; do not print | Purchased6088x22x7 envelope only; not selection/approval.
R01_AX12A_body_REFERENCE | motor envelope; do not print | Exact nominal body envelope32x50x40; connectors/horn/case details omitted.
R02_XM430_body_REFERENCE | motor envelope; do not print | Exact nominal body28.5x46.5x34; connector/horn offsets omitted.
P18_AX_wrist_bridge | development print | Trial motor clearance0.4per side on width. Wrist assembly brackets and clearances pending.
P19_gripper_base_plate | development print | Separate seventh AX motor. Two opposed racks plus guides. Motor fixed body bracket not yet released.
P20_gripper_pinion_20T_M1p5 | development print | Pitch radius15mm; nominal rack pitch lines30mm apart;0.16mm tooth backlash per gear.
P21_gripper_rack | development print | M1.5 rack. Oppose second rack with180deg rotation. Guide clearance must be coupon-tuned.
P22_gripper_guide_rail | development print | Trial rail; retained sliders need cover/spacer stack verification.
P23_gripper_finger | development print | Rigid prototype jaw. Fastening to rack end needs revised match and pad selection before assembly.

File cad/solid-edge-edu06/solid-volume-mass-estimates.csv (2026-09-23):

part | CAD_volume_mm3 | solid_PLA_mass_g_at_1.24g_per_cm3 | status
C01_clearance_and_M3_nut_coupon | 11830.45 | 14.67 | fit coupon
P01_AX_horn_adapter | 3218.88 | 3.99 | fit coupon
P02_XM_horn_adapter | 3152.4 | 3.91 | fit coupon
P03_XM_side_mount_coupon | 3549.48 | 4.4 | fit coupon
P04_AX_body_mount_plate | 7314.41 | 9.07 | development print
P05_base_plate | 157233.35 | 194.97 | development print
P06_turntable_interface_ring_PROVISIONAL | 102909.9 | 127.61 | development print
P07_base_gear_60T_M2 | 61175.8 | 75.86 | development print
P08_base_pinion_20T_M2 | 9132.17 | 11.32 | development print
P09_shoulder_gear_80T_M1p5 | 65526.13 | 81.25 | development print
P10_elbow_gear_40T_M1p5 | 20297.28 | 25.17 | development print
P11_XM_pinion_20T_M1p5 | 4739.48 | 5.88 | development print
P12_shoulder_bearing_cheek | 61582.78 | 76.36 | development print
P13_upper_link_cheek_120 | 15578.71 | 19.32 | development print
P14_forearm_cheek_100 | 15475.77 | 19.19 | development print
P15_cross_tie_50 | 9146.04 | 11.34 | development print
P16_upper_box_skin | 10472.84 | 12.99 | development print
P17_forearm_box_skin | 8072.84 | 10.01 | development print
R03_608_bearing_REFERENCE | 2309.07 |  | purchased reference; do not print
R01_AX12A_body_REFERENCE | 64000 |  | motor envelope; do not print
R02_XM430_body_REFERENCE | 45058.5 |  | motor envelope; do not print
P18_AX_wrist_bridge | 5393.93 | 6.69 | development print
P19_gripper_base_plate | 20141.79 | 24.98 | development print
P20_gripper_pinion_20T_M1p5 | 3654.33 | 4.53 | development print
P21_gripper_rack | 2535.27 | 3.14 | development print
P22_gripper_guide_rail | 5614.73 | 6.96 | development print
P23_gripper_finger | 4025.71 | 4.99 | development print

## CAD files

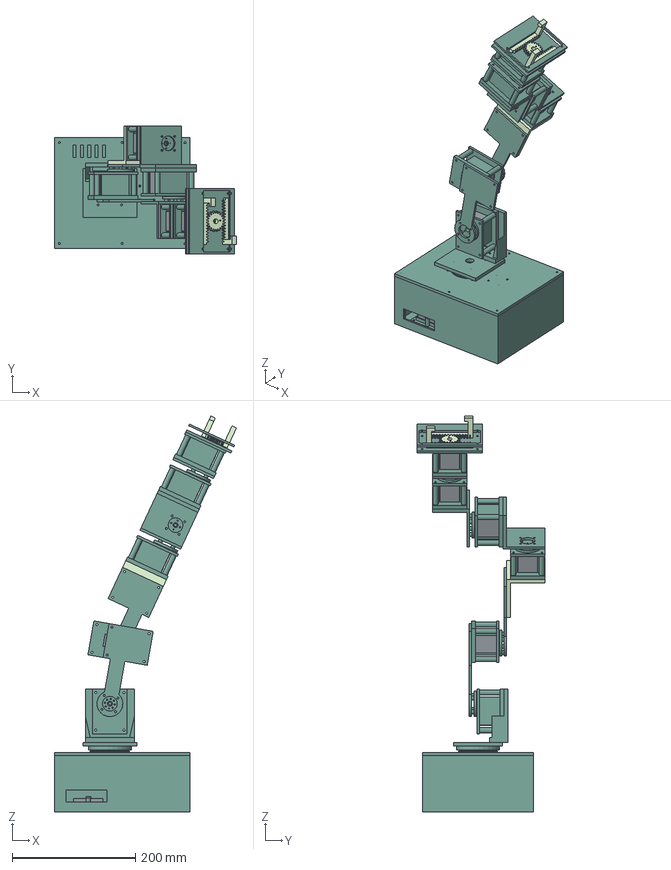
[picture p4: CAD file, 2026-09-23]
cad/solid-edge-edu06-r02/EDU06_R02_ASSEMBLY.stp
295.7 x 207.5 x 643.5 mm
B01b_open_base_box
B02c_removable_structural_lid
B03b_yaw_bearing_cartridge
B04_bearing_outer_race_cap x 2
H01_61806_30x42x7 x 2
B05_yaw_gear_60T
B06_hollow_yaw_spindle
H_AX_motor_case x 5
H_AX_motor_horn x 5
M_AX_keyed_cradle x 5
M_AX_rear_cap x 5
B07b_supported_yaw_pinion_20T
B11_pinion_bearing_hanger
B12_pinion_bearing_cap
H02_608_8x22x7
B08_motor_floor_spacer x 4
B09b_U2D2_service_tray
H_U2D2_48x18x14p9
B10_U2D2_retaining_strap
A01_rotating_platform
A02b_shoulder_pedestal
H_XM_motor_case x 2
H_XM_motor_horn x 2
M_XM_keyed_cradle x 2
M_XM_rear_cap x 2
M_XM_output_flange_b x 2
A03_output_spacer_4 x 20
A04b_upper_link_100
A05b_forearm_link_85
A06b_wrist_right_angle_bracket
M_AX_output_flange x 3
A07b_wrist_rotor_platform
A09_left_wrist_rotor_platform
A08_tool_mount
G01_fixed_gripper_guide_plate
G04_guide_cover
G02_gripper_pinion_20T
G03_integral_rack_and_finger x 2

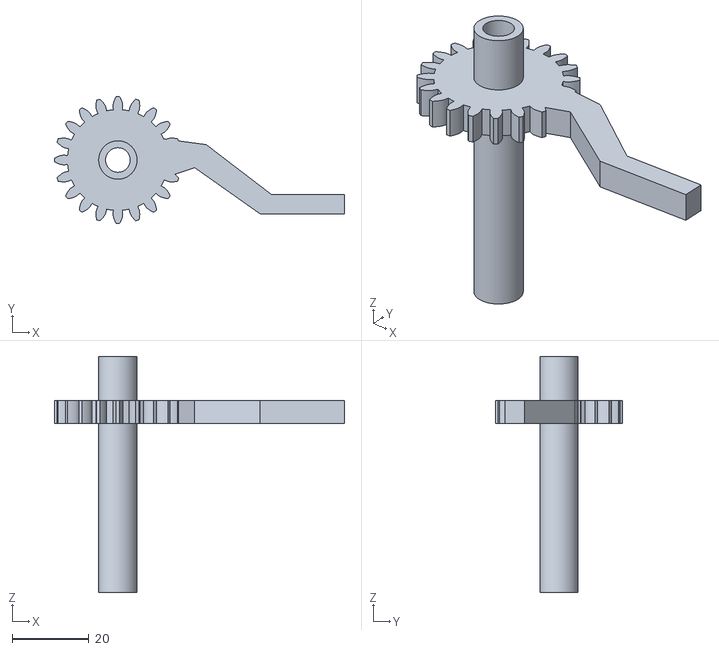
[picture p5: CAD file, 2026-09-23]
cad/blender-edu06-r03/prototype_stl/G06_idler_gear_jaw.stl
75.5 x 33.0 x 61.5

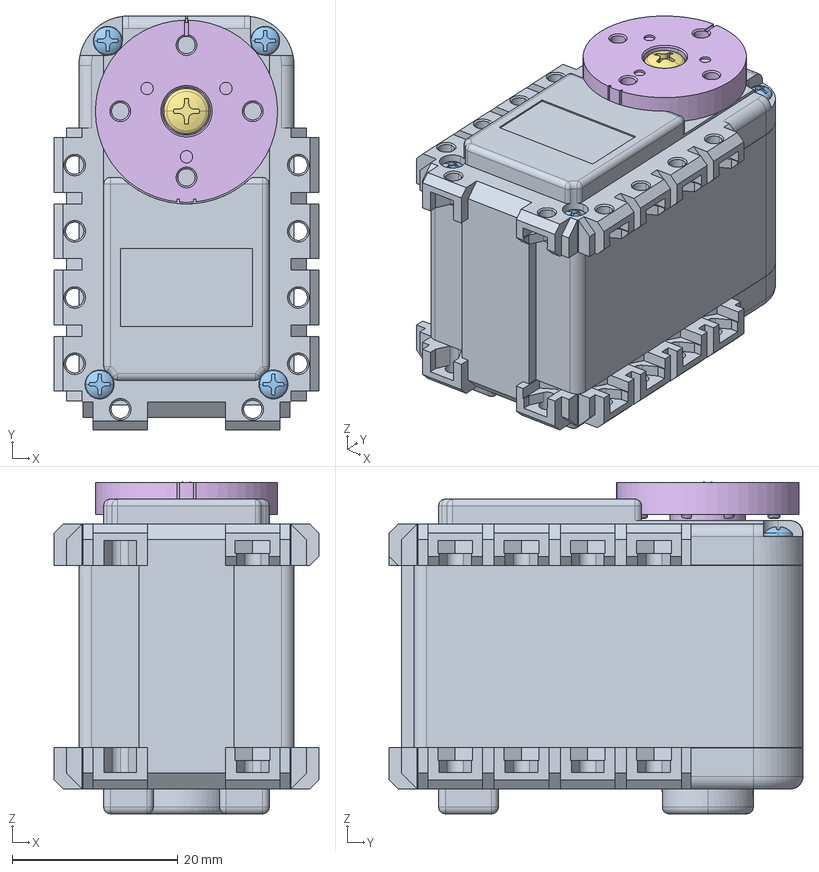
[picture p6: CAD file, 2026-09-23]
cad/blender-edu06-r04/motor-references/AX-12A.stp
32.0 x 50.0 x 40.0 mm
PRT0001
PRT0002
PRT0003 x 4
PRT0004 x 2
PRT0005
PRT0006
PRT0007

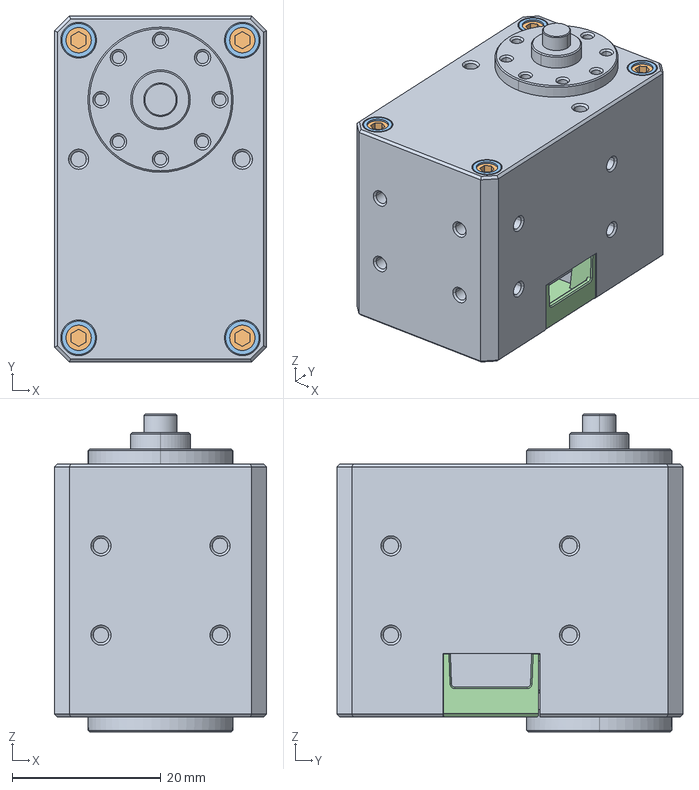
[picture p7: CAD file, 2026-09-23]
cad/blender-edu06-r05/motor-references/XM_H-430_idler.stp
28.5 x 46.5 x 42.7 mm
DUMMY_DC12_3
WBH_M2_5X12_8 x 8
DC12_A01_SPACER_RING_1_2 x 8
DC12_A01_CVR_CABLE_5_1

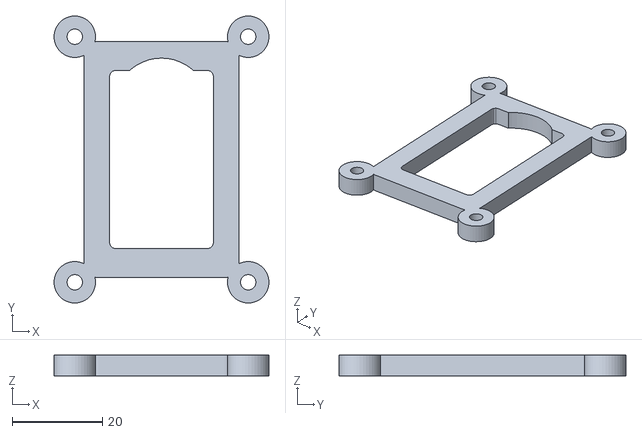
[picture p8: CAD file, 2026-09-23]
cad/blender-edu06-r05/prototype_stl/S_XM_C02_Connector_access_rear_cap.stl
47.7 x 63.7 x 4.60

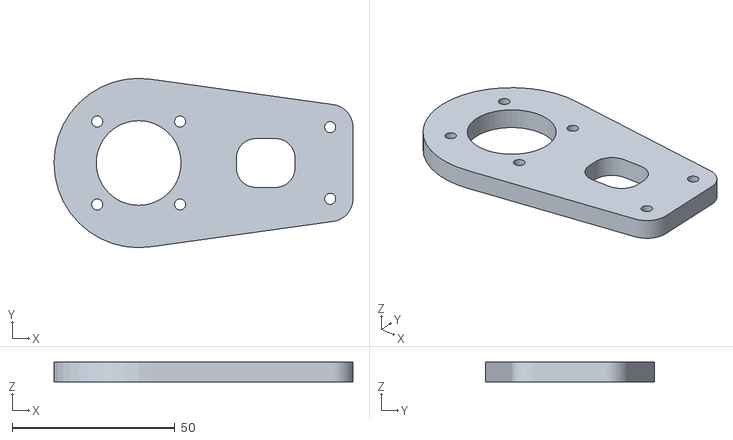
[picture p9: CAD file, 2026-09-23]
cad/blender-edu06-r06/prototype_stl/A03_left_forearm_fork.stl
91.8 x 52.0 x 6.00

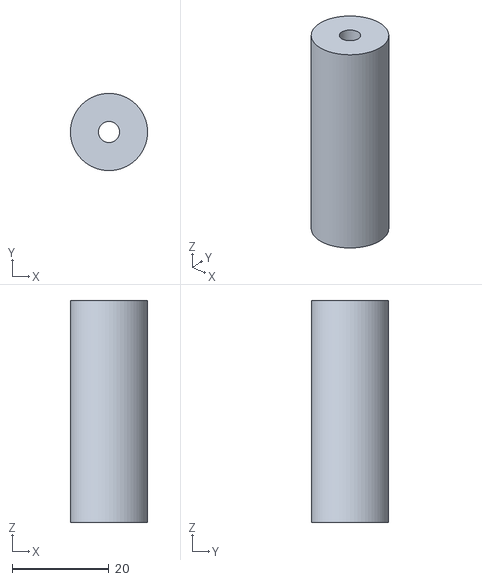
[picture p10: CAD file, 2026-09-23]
cad/prototype_stl/P07_upper_spacer.stl
16.0 x 16.0 x 46.0

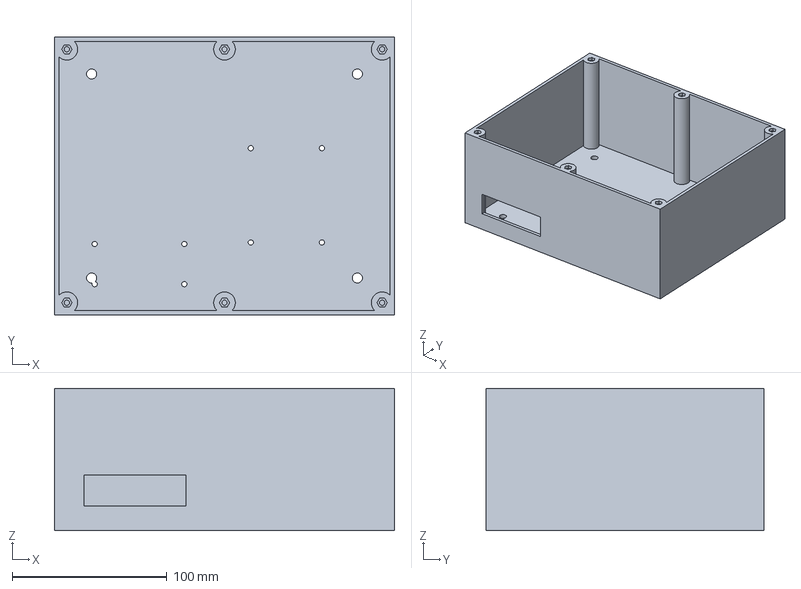
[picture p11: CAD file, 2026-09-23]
cad/solid-edge-edu06-r02/step/B01b_open_base_box.stp
220.0 x 180.0 x 92.0 mm

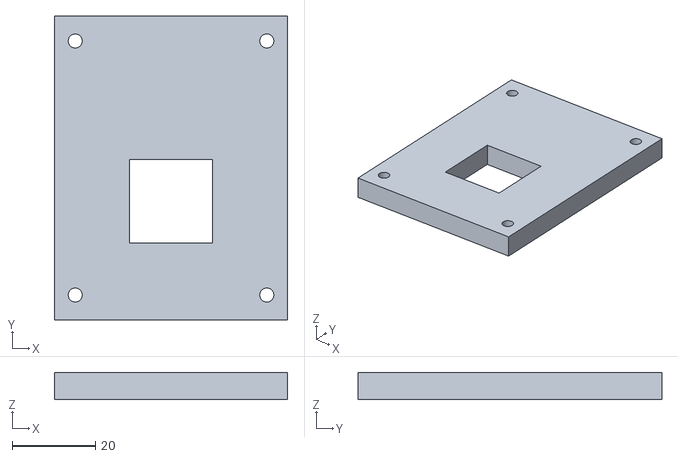
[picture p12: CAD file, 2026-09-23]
cad/solid-edge-edu06-r02/stl_mm/M_AX_rear_cap.stl
56.0 x 73.0 x 6.50

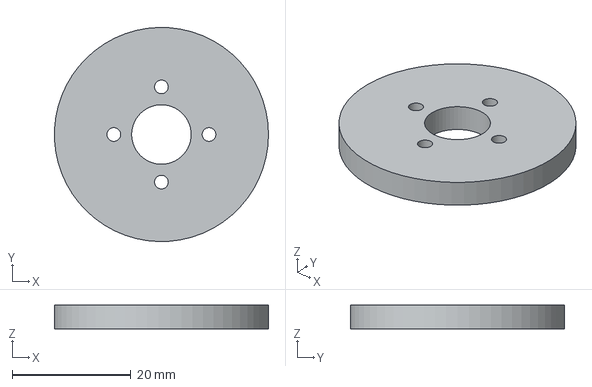
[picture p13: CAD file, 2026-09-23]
cad/solid-edge-edu06/development-api-probes/AX_horn_adapter_ordered.stp
36.0 x 36.0 x 4.00 mm

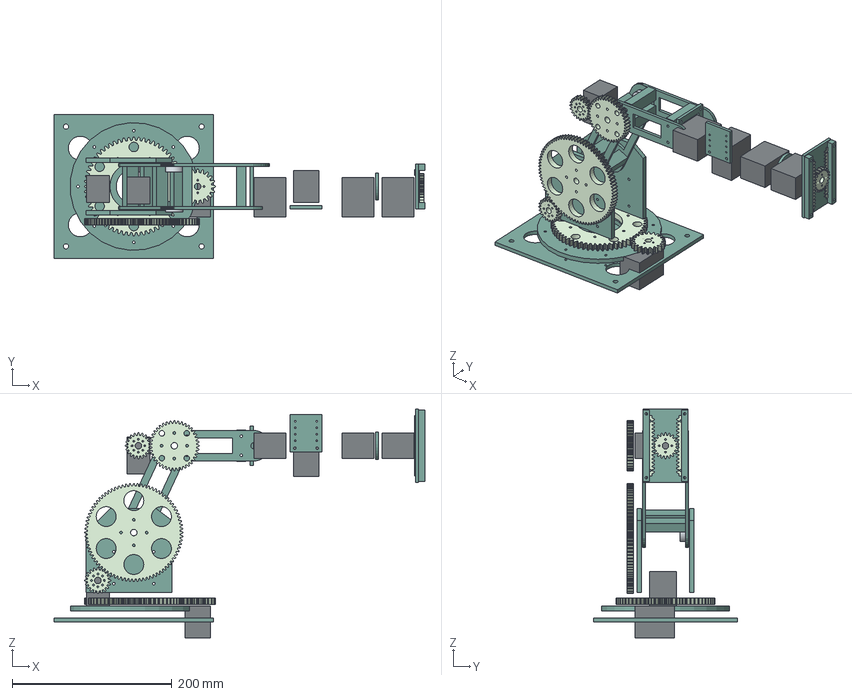
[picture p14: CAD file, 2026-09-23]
cad/solid-edge-edu06/EDU06_R01_LAYOUT_PROTOTYPE.stp
464.7 x 180.0 x 286.8 mm
P05_base_plate
P06_turntable_interface_ring_PROVISIONAL
P07_base_gear_60T_M2
P08_base_pinion_20T_M2
R01_AX12A_body_REFERENCE x 5
P12_shoulder_bearing_cheek x 2
P09_shoulder_gear_80T_M1p5
P11_XM_pinion_20T_M1p5 x 2
R02_XM430_body_REFERENCE x 2
P13_upper_link_cheek_120 x 2
P15_cross_tie_50 x 8
P10_elbow_gear_40T_M1p5
P14_forearm_cheek_100 x 2
R03_608_bearing_REFERENCE x 4
P18_AX_wrist_bridge
P04_AX_body_mount_plate
P01_AX_horn_adapter
P19_gripper_base_plate
P20_gripper_pinion_20T_M1p5
P21_gripper_rack x 2
P22_gripper_guide_rail x 2

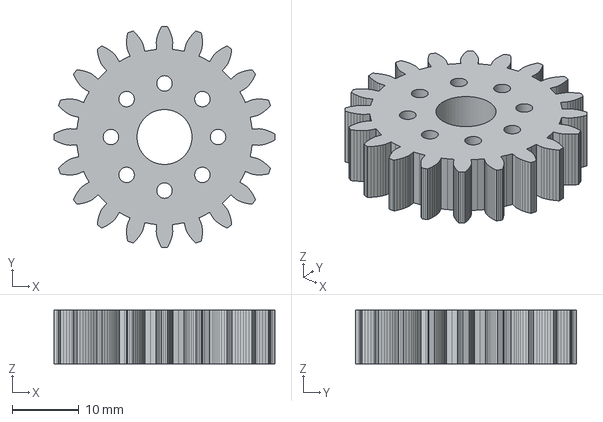
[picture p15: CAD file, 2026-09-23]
cad/solid-edge-edu06/step/P11_XM_pinion_20T_M1p5.stp
33.0 x 33.0 x 8.00 mm

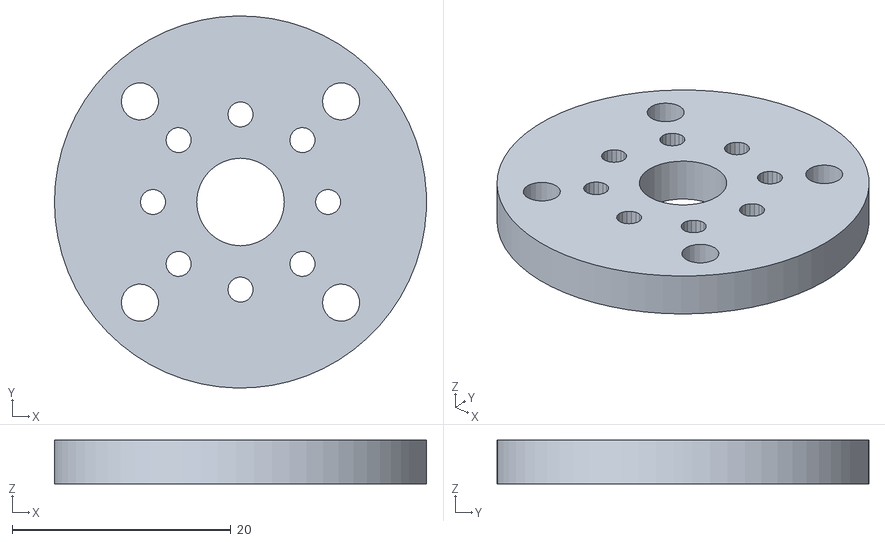
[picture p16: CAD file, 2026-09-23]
cad/solid-edge-edu06/stl_mm/P02_XM_horn_adapter.stl
34.0 x 34.0 x 4.00

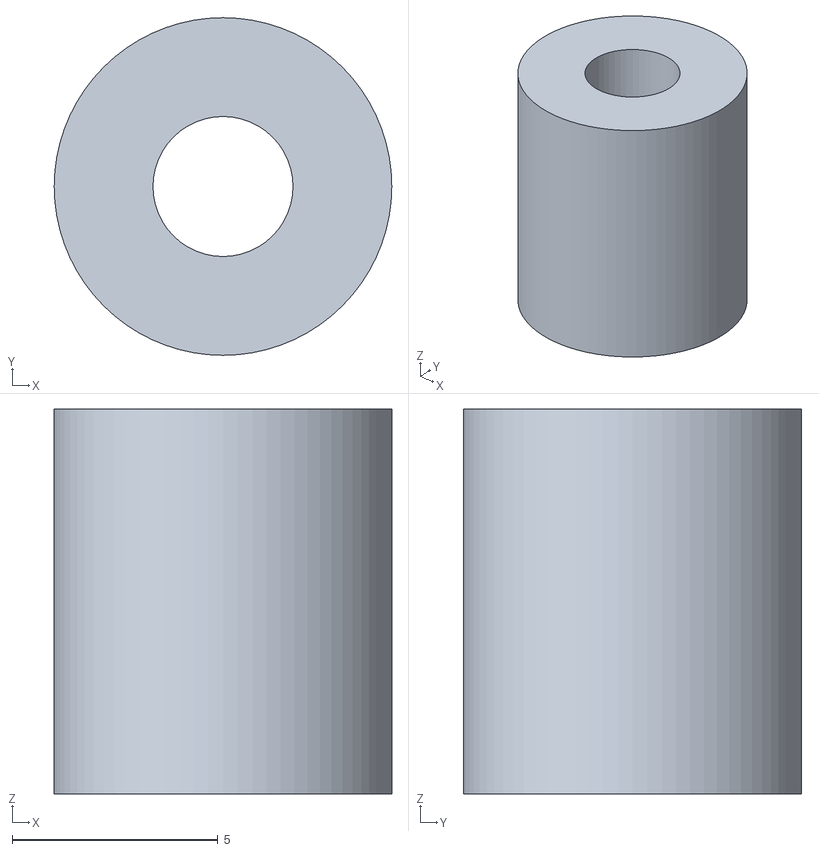
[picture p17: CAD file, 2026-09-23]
cad/blender-edu06-r03/prototype_stl/E_09_motor_mount_standoff_0.stl
8.20 x 8.20 x 9.35

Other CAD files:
cad/blender-edu06-r04/motor-references/AX_front_shim_single_U_verification.stl
cad/blender-edu06-r04/prototype_stl/E_XM_C02_Connector_access_rear_cap.stl
cad/EDU05_robot_arm_concept.blend
cad/blender-edu06-r03/EDU06_R03.blend
cad/blender-edu06-r03/prototype_stl/A01_hollow_ribbed_link.stl
cad/blender-edu06-r03/prototype_stl/A01_root_bolt_spacer_0.stl
cad/blender-edu06-r03/prototype_stl/A01_root_bolt_spacer_1.stl
cad/blender-edu06-r03/prototype_stl/A01_root_bolt_spacer_2.stl
cad/blender-edu06-r03/prototype_stl/A01_root_bolt_spacer_3.stl
cad/blender-edu06-r03/prototype_stl/A02_elbow_spacer_0.stl
cad/blender-edu06-r03/prototype_stl/A02_elbow_spacer_1.stl
cad/blender-edu06-r03/prototype_stl/A02_elbow_spacer_2.stl
cad/blender-edu06-r03/prototype_stl/A02_elbow_spacer_3.stl
cad/blender-edu06-r03/prototype_stl/A03_hollow_ribbed_link.stl
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

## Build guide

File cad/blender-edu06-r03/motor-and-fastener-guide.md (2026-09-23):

# EDU06 R03 motor and fastener guide

This guide describes the current Blender generator's motor interfaces and fastening stacks. It is a prototype assembly guide, not evidence of physical fit, carrying capacity or successful powered operation. Dimensions are millimetres. Check the final `motor-interface-schedule.json` against the supplied hardware before printing the complete arm; that schedule records each generated motor transform and fastening stack.

## Materials and purchased components

Fabricated cradles, caps, shafts, bearings, gears, links, spacers and feet are printed filament. The additional fastening hardware is screws and nuts. Motors retain their supplied cases, horns, centre screws and internal components. Electronics and cables are purchased components. No added metal bearing, shaft, guide rod, bracket or washer is specified by these motor assemblies.

## Motor datum and verified interfaces

For every motor, local `(0,0,0)` is the **front face of its installed horn**. The output axis is local **+Z**; case height follows local **Y**. Parent transforms in the interface schedule place this datum into the arm. The motor output axis is not the centre of the rectangular case.

| Dimension or coordinate | AX-12A | XM430-W350-T |
|---|---:|---:|
| Published width × height × depth | 32 × 50 × 40 | 28.5 × 46.5 × 34 |
| Case top Y / bottom Y | +11.50 / −38.50 | +11.25 / −35.25 |
| Main case front Z / back Z | −4.00 / −36.00 | −2.20 / −36.20 |
| Rearmost modeled case Z | −40.00 | −36.20 |
| Installed reference depth, horn front to rearmost case | 40.00 | 36.20 |
| Front cradle bezel Z, back to front | −3.65 to −1.05 | −1.85 to −0.25 |
| Rear-cap front Z / rear Z | −40.35 / −44.95 | −36.55 / −41.15 |
| Four cradle-post X coordinates | ±21.00 | ±19.25 |
| Cradle-post Y coordinates | +15.50, −42.50 | +15.25, −39.25 |
| Cradle rectangular hole-centre spacing | 42.00 × 58.00 | 38.50 × 54.50 |

The AX main body, front horn and rear projections are modeled separately within its 40 mm installed depth. The XM published 34 mm case depth has a separately modeled 2.2 mm front horn projection. These envelope models do not reproduce every manufacturer surface feature. Connector details in Blender illustrate the access space; compare actual plugs and wires with the printed rear window.

The AX horn has four M2 holes on a 16 mm pitch circle: `(8,0)`, `(0,8)`, `(−8,0)`, `(0,−8)`. The XM reference horn has eight M2 holes on the same pitch circle, spaced 45 degrees apart. Manufacturer drawing thread-depth limits used here are 4 mm for AX and 2 mm for the inspected XM horn. Confirm the supplied horn revision before attaching a printed part. The cradles locate the motor case mechanically and do not rely on guessed motor-body mounting holes.

Manufacturer references: [AX-12A eManual](https://emanual.robotis.com/docs/en/dxl/ax/ax-12a/), [AX dimensional drawing](https://emanual.robotis.com/assets/images/dxl/ax/ax-12a_dimension.png), [XM430 eManual](https://emanual.robotis.com/docs/en/dxl/x/xm430-w350/), and the locally retained ROBOTIS XM dimensional drawing described in `research-motors.md`.

## Cradle fit and rear fastening

Each cradle provides 0.35 mm nominal clearance per case side and a 26 mm front horn window. Its rear cap is 4.6 mm thick. Two removable 0.30 mm axial shims reduce the modeled total front/rear clearance from 0.70 to 0.10 mm. These are initial print-fit allowances, not guaranteed printed results.

The **four M3 nuts are captive at the front of the cradle posts**. Their pockets are 5.8 mm across flats and 2.8 mm deep. Posts have a 4.6 mm radius, leaving approximately 1.25 mm of plastic outside the nut-pocket corners. The reference M3 nut is 5.5 mm across flats and 2.4 mm thick. All through holes in this stack are 3.4 mm diameter.

Screws enter from behind the supporting wall, through the rear printed spacer, supporting wall and any structural standoff, rear cap, and cradle post. Their shafts point along local +Z into the front captive nuts. Screw heads and length-adjusting spacers therefore remain behind the motor mounting structure, clear of the front gear plane. There are no additional rear-cap nuts or duplicate outer nuts.

The following table is derived from the current `make_motor` function and builder attachment depths. Each listed unit has four identical M3 screws, four front M3 nuts, and four rear spacers.

| Unit | Motor | Attachment depth behind cap | Screw, under-head length | Rear printed spacer thickness |
|---|---|---:|---:|---:|
| J1 base rotation | AX | 20.05 | M3 × 65 | 1.15 |
| J2 shoulder | XM | 15.35 | M3 × 60 | 3.85 |
| J3 elbow | XM | 15.35 | M3 × 60 | 3.85 |
| J4 forearm roll | AX | 6.00 | M3 × 50 | 0.20 |
| J5 wrist pitch | AX | 4.00 | M3 × 50 | 2.20 |
| J6 tool roll | AX | 4.00 | M3 × 50 | 2.20 |
| Separate gripper actuator | AX | 12.00 | M3 × 60 | 4.20 |

This motor-cradle subtotal is **4 M3×65, 12 M3×60, 12 M3×50 and 28 M3 nuts**. It excludes other arm, gear, journal and enclosure fasteners. Use the rear-spacer STL belonging to that particular motor; similar-looking spacers have different thicknesses.

The calculation uses `B = rear_cap_back`, `D = attachment_depth`, `F = front_bezel_front`, all in the motor frame:

```text
rear wall outer plane = B − D
front nut top        = F − 0.20
front nut bottom     = F − 2.60
target screw tip     = F − 0.10
screw length         = 5 × ceil((target tip − rear wall outer plane) / 5)
under-head Z         = target screw tip − screw length
rear spacer thickness = rear wall outer plane − under-head Z
```

The nominal tip projects 0.10 mm beyond the nut while remaining 0.10 mm behind the cradle front plane. Inspect the actual assembled stack: printed thickness errors and screw-length tolerances can change this small clearance. The old `attachment_nut_recess` argument is deprecated and does not affect this calculation.

The base has separately printed **8 mm feet** to provide underside screw-head clearance. Preserve those feet and the supporting floor/standoff arrangement. Reference socket heads are M2 Ø3.8 × 2 mm high, M3 Ø5.5 × 3 mm high, and M4 Ø7 × 4 mm high. Match the actual purchased head profiles and allow driver access, especially behind the wrist.

The five enclosure-lid nuts and four rotating-deck flange nuts are **loaded through side slots**, leaving plastic roofs above them to react the upward bolt pull. Insert these nuts before closing their access. Lid pockets occupy Z85.2–88.0 with 2 mm roofs; their M3×12 screws remain under-head Z95. The rotating flange pockets occupy Z106.8–109.6 with 2.4 mm roofs. Its four M3×12 screws use 0.8 mm printed spacers above the deck: heads seat at Z118.8 and tips end at Z106.8, above the collar that ends at Z106. These coordinates are in the fixed base frame for the lid and the yaw frame for the rotating flange.

## Horn screw stacks

Screw length below the head minus the complete printed stack gives nominal thread penetration. The values below assume no additional washer. Retain the manufacturer's central horn-retaining screw and leave access to it.

| Interface | Quantity per actuator | Screw | Printed stack under head | Nominal horn penetration | Drawing depth limit |
|---|---:|---|---:|---:|---:|
| AX J4/J5/J6 raised output adapter | 4 | M2 × 10 | 7.0 | 3.0 | 4.0 |
| AX J1 yaw pinion | 4 | M2 × 6 | 4.0 counterbore floor | 2.0 | 4.0 |
| AX driven gripper gear | 4 | M2 × 6 | 4.0 counterbore floor | 2.0 | 4.0 |
| XM J2/J3 pinion | 8 | M2 × 6 | 4.5 counterbore floor | 1.5 | 2.0 |

This horn-fastener subtotal is **12 M2×10 and 24 M2×6**. The supplied motor-centre screws are additional retained hardware. The modeled M2 clearance diameter is 2.3 mm. Check actual under-head length and printed floor thickness with calipers, particularly the XM stack with its 0.5 mm nominal depth margin. Do not tighten a screw that bottoms before the printed adapter seats.

## Fit trials and assembly sequence

1. Confirm the actual actuator labels, supplied horns, nut dimensions, screw lengths and head profiles. Keep the motors unpowered while fitting brackets. Print the general hole/nut coupon first on the Bambu A1 using the intended filament and print settings. Its ranges are Ø3.2/3.4/3.6, Ø8.3/8.5/8.7 and 5.6/5.8/6.0 mm across-flats pockets.
2. Print the separate `F02_AX_16PCD_horn_coupon` and `F02_XM_16PCD_horn_coupon` before their gears. They provide unobstructed four-hole and eight-hole patterns respectively, both on a 16 mm pitch circle. The AX coupon is 4 mm thick and the XM coupon is 4.5 mm thick; M2×6 gives the same nominal 2 mm / 1.5 mm engagement as their corresponding pinion floors. F01 is exclusively the general hole/nut-fit coupon.
3. Print one cradle, cap and matching shims as a physical sample. Remove supports and any burrs from seating faces, bores and nut pockets. Check that nuts seat without splitting the posts, the case slides in without force, the horn remains free, and both connector plugs can be inserted and removed. Adjust clearance or shim thickness from measurements; keep the manufacturer hole-centre coordinates fixed.
4. Insert the four front captive nuts before installing gears that would obstruct access. Place the front shim against the cradle retaining lip; insert the motor from the rear with its horn through the 26 mm window. Add the rear shim and cap. Check seating before tightening anything.
5. Align the cradle, structural standoffs and supporting wall with the four scheduled hole centres. Place the appropriate rear spacers behind that wall, then insert the scheduled M3 screws from the rear. Tighten evenly only enough to seat the stack. Confirm that the case is retained without distortion and that the front tips remain recessed. Nut retention and tightening torque require physical validation; no tightening torque is prescribed here.
6. Fit the horn adapter or pinion using its M2 stack from the table. Check central-screw access and screw-head counterbores before fitting an outboard support that covers them. Test each printed journal and mating bore as a small physical sample. Confirm free rotation, axial clearance and gear contact before loading the complete arm; do not force a stationary servo gearbox by pulling on a long link.
7. Inspect the assembled range slowly while supporting the arm. Check rear screw heads, gear sweeps, printed thrust faces and real cable service loops. STL mesh checks and Blender animation do not establish friction, wear, creep, temperature rise or payload. Those require staged physical testing before powered use under load.

Very thin rear spacers and the 0.30 mm motor shims need suitable layer settings and a measured result. Select print orientation and supports to preserve the motor lips, nut-pocket walls, journal surfaces and load-bearing layers. Do not interpret a closed STL or a successful slicer preview as proof that those features will fit or carry the required moment.

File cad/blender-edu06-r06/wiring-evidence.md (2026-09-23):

# H06 gripper wiring evidence

The J5-to-gripper harness uses the existing Ø26 mm fixed wrist heel opening, an external service loop, and the gripper's 20 × 10 mm rear passage with its 20 mm open assembly gap. Motor connector datums and printed geometry were not changed to route it. `gripper_wiring_guides.py` contains the local guide coordinates.

The supplemental checks used a separate native test scene built from the completed R06 mechanical assembly:

| Check | Recorded result |
|---|---|
| 31 animation frames | Endpoints attached; no sampled structure/gear contact; bend and strand-spacing targets met |
| 19 named operating poses, including combined arm limits | Same checks passed |
| 275 wrist combinations at 5° increments; 401 points per curve | Minimum individual-wire radius **12.263 mm**, against the provisional 12 mm target |
| Closest sampled wire-to-polyline spacing across those wrist combinations | **1.573 mm** between wire centres, versus **1.44 mm** modelled insulation diameter |

Native forward/backward frame transport keeps the wire layout consistent around bends. Three external loop guides use 2.4 mm wire-centre pitch; constrained passages retain the default 1.8 mm pitch and connector endpoints retain 2.5 mm pin pitch. Checking only equal curve parameters would miss wires that touch at neighbouring parameters; the supplementary spacing check compares each sampled point to nearby segments of the other wires.

These results are summarized in [H06-route-evidence.json](H06-route-evidence.json). The final delivery-wide [wiring-audit.json](wiring-audit.json), [wiring-operating-range-audit.json](wiring-operating-range-audit.json) and [wiring-kinematics-audit.json](wiring-kinematics-audit.json) govern the delivered native model.

This is a kinematic routing prototype. The geometric route length varies with motion; guide empties are not installed clips. These checks do not establish constant cable length, connector fit, strain relief, fatigue, continuous swept clearance or contact between separate harnesses. Select and measure the actual cables, then fit their retention and verify full unpowered travel before operation. Electrical assumptions and connector families are in [wiring-notes.md](wiring-notes.md).

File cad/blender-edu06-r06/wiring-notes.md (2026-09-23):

# EDU06 R06 wiring and service routing

The six motors share one half-duplex TTL bus. They are addressed peers and parallel electrical loads. The drawing's physical cable order is:

`PC USB → U2D2 → external power-injection junction → J1 AX → J2 XM → J3 XM → J4 AX → J5 AX → gripper AX`

An external regulated supply injects VDD and GND at the junction. **U2D2 does not supply motor power.** The junction shown in Blender is a generic reserved envelope; its particular board, fuse, current rating and terminals have not been selected. The separate slotted mounting plate is adaptable, not a claim of a verified PCB hole pattern. U2D2's published case envelope is 48 × 18 × 14.9 mm. Its USB revision must be checked: ROBOTIS changed from Micro-B to USB-C in August 2025. [ROBOTIS U2D2 manual](https://emanual.robotis.com/docs/en/parts/interface/u2d2/)

## Connector families and polarity

| Motor/interface | Cable housing | Pin 1 | Pin 2 | Pin 3 |
|---|---|---|---|---|
| AX-12A | Molex 50-37-5033 | GND | VDD | DATA |
| XM430-W350-T | JST EHR-03 | GND | VDD | DATA |
| U2D2 TTL | JST EHR-03 | GND | VDD | DATA |

The XM-to-AX links require the correct Molex–JST conversion cable; the housings are mechanically different. ROBOTIS specifies 21 AWG cable for these interfaces. The model's black/red/yellow colors mean GND/VDD/DATA; do not infer physical pin order from a camera view or a third-party cable's colors. Check the keyed connector orientation and numbered pins on the actual hardware before powering it. [AX connector specification](https://emanual.robotis.com/docs/en/dxl/ax/ax-12a/#connector-information), [XM connector specification](https://emanual.robotis.com/docs/en/dxl/x/xm430-w350/#connector-information), [ROBOTIS XM package and conversion cable](https://en.robotis.com/shop_en/item.php?it_id=902-0124-000)

## What the connector geometry establishes

All motor coordinates use the installed stock-horn front as Z = 0, output along +Z, case height along Y.

- **AX:** the two separately identified official STEP headers have X ranges −9.9…0 and 0.1…10.0 mm, Y −17.62…−12.72 mm and Z −33.70…−24.30 mm. Rear-facing connector route datums are at X −4.95/+5.05, Y −15.17, Z −33.70 mm.
- **XM:** the official STEP cable cover has openings on both **side faces**, X = ±14.25 mm. Their centre is Y = −14.55 mm; the visible opening extends approximately Z −32.20…−27.55 mm. Route datums use Z = −29.875 mm and the outward direction ±X. These are case-exit datums; the simplified CAD does not establish the hidden electrical contact depth.
- The displayed cable plug envelopes are provisional purchased-part references. They are not printable housings and do not establish verified connector engagement. Measure actual plug bodies, latch access and crimp exits before manufacturing adjacent guides.
- The final gripper's second socket is intentionally unused. No unattached cable is placed there.

The motor solids are the official ROBOTIS STEP tessellation already documented in `motor-references/README-official-cad.md`. Printed cradles retain access to the AX rear sockets and XM side exits. Cable clearance still needs to be checked with the actual supplied housing/latch revision.

## Bus configuration

Assign six unique IDs, for example 1–6 in the physical order above. Set a common supported baud rate before connecting the full chain; 1 Mbps is a supported candidate. AX uses Protocol 1.0; XM defaults to Protocol 2.0. A controller retaining that mixed configuration must send model-specific packet formats sequentially on the same half-duplex bus, use the correct control-table addresses, and avoid overlapping replies. XM can be switched to Protocol 1.0, but that can restrict access to some control-table areas; this design does not silently change the motors' configuration. [AX control table](https://emanual.robotis.com/docs/en/dxl/ax/ax-12a/), [XM Protocol Type and baud-rate settings](https://emanual.robotis.com/docs/en/dxl/x/xm430-w350/#protocol-type13), [ROBOTIS SDK](https://emanual.robotis.com/docs/en/software/dynamixel/dynamixel_sdk/overview/)

## Power is an unresolved hardware selection

At 12 V, published stall currents total **10.6 A**: four AX motors at 1.5 A and two XM motors at 2.3 A. Stall is an exceptional operating condition, not a continuous design target. This sum does **not** rate the first cable, connector, power junction or supply. With a single upstream feed, early harness sections carry the sum of downstream currents. Choose protective current limits and rated distribution hardware, then measure voltage drop and connector temperature under the intended load. Additional fused VDD/GND feeds may be needed; DATA remains the common TTL bus. No safe simultaneous full-stall operating condition is claimed. [AX electrical specification](https://emanual.robotis.com/docs/en/dxl/ax/ax-12a/#specifications), [XM electrical specification](https://emanual.robotis.com/docs/en/dxl/x/xm430-w350/#specifications)

## Mechanical route and Blender behavior

The old decorative motor looms and service leads are removed. Every new conductor uses a NURBS spline whose control coordinates are driven by native world-space transform variables. Both endpoints follow connector-attached empties; intermediate guides follow the relevant rigid link or a weighted moving service loop. Forward and backward parallel-transport frame chains use native rotation/track constraints to orient the separate conductors. The connector pin-row orientations are retained. This dependency network survives saving/reopening without a frame handler or an auto-run Python script.

The base USB jacket is 4.7 mm in diameter through the 5.2 mm split saddle; the external DC jacket is 5.6 mm through the 6.4 mm saddle. These are routing assumptions, not measurements of the user's cables. Saddle axes and rear wall openings come from `base_module.py`; use its actual screw/nut stack. The front accessory bay is kept reserved. The fixed-to-yaw loom uses the hollow yaw shaft, with allowance for the limited yaw range rather than unlimited rotation.

`wiring-connectivity.json` records connector endpoints, cable families, conversion links, conductor colors and native guide names. `audit_wiring.py` checks 31 animation frames for endpoint attachment, approximate minimum curve radius, route-length variation and clearance to actual printed parts and manufacturer motor cases. `--operating-range` additionally checks the 19 named within-limit poses generated by the independent mechanical auditor, including individual extremes, combined extremes and wrist corner poses. These discrete screens do not prove every point of the continuous workspace.

The clearance envelope follows the actual evaluated outer conductors plus their 0.72 mm assumed insulation radius. Connector pin pitch is 2.5 mm; intermediate bundle pitch defaults to 1.8 mm, with explicit guide overrides up to 3.0 mm on selected free loops and strain-relief approaches to keep the insulation separate. Each actual guide pitch is recorded in the connectivity manifest. Nearest sampled point-to-polyline distances check strand separation against the 1.44 mm modelled insulation diameter. The only motor-case exemption is that endpoint's own case within 18 mm of its wire exit, on the outward side of the matching port mouth; no printed parts or other motor cases receive that exemption. Hidden plug engagement remains provisional. Fixed USB and DC jacket screening is reported separately because those routes have intentional close-fitting saddle interfaces.

The initial bend-radius target is 12 mm; replace it with the selected cable manufacturer's dynamic bend specification. Provisional cut lengths include additional slack beyond the sampled maximum geometric route. Upper service-loop control anchors are kinematic references, not additional installed printable clips. The modelled screw clamps retain the base USB and power jackets; upper-link cable retention and strain relief still need to be established using the selected cables and physical travel checks.

Strand-spacing checks compare the three conductors within each harness. They do not establish clearance between different harnesses or an exhaustive self-contact solution for a flexible cable.

The wire curves do not have separately weighed masses or measured centres of mass. The load audit uses a 10% lumped moving-mass allowance for screws and wiring; it has not been verified against the actual selected harness and hardware. Weigh the finished moving harness and fasteners before treating the payload estimate as established.

## Final saved-model checks

The final R06 model passed the complete 31-frame animation screen and 19 named operating-pose screen. Each contains all seven TTL harnesses and 28 curves: seven route centrelines and 21 conductors. All five checks passed: attached endpoints, gear clearance, printed-part/motor-case clearance, at least 12 mm sampled conductor bend radius, and separation of the three conductors within each harness.

Across those 50 samples, the minimum conductor bend radius was **12.176 mm**, the minimum within-harness strand centre separation was **1.481 mm** against 1.44 mm modelled insulation diameter, and the minimum structural envelope gap was **0.596 mm** against the 0.5 mm screen target. Maximum endpoint drift was **0.000 mm**. The final reports are `wiring-audit.json`, `wiring-operating-range-audit.json` and the compact `wiring-final-summary.json`; fixed USB/DC jackets have their own `fixed-jacket-audit.json`.

The seven provisional segment cut lengths total **3.33 m of three-conductor harness** (9.99 m of individual conductor before trimming). These include the chosen slack allowance and use the largest sampled conductor path, not just the centreline. They remain fitting estimates: select the real connectors/cable and prove free travel before cutting the final harness.

**This is a geometric kinematic harness, not a constant-length flexible-body simulation.** Curve shape changes do not prove insulation strain, torsional life, latch retention, continuous swept clearance or fatigue. A failed route audit must be fixed or reported as unresolved. Before powered operation, assemble the actual cables, move all axes through their limits by hand with power off, verify that no cable is pulled taut or can enter teeth, and secure the final guides without pinching insulation.

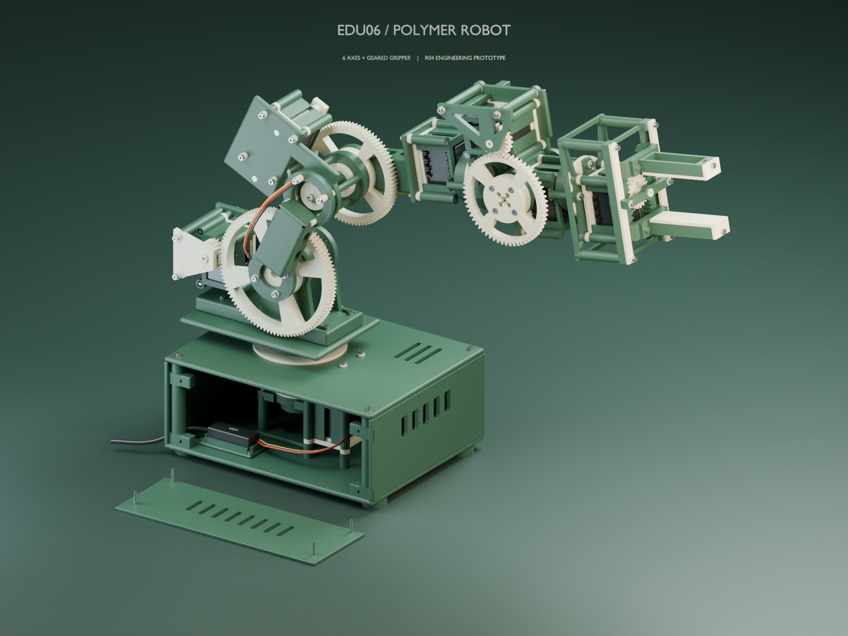
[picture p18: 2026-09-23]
cad/blender-edu06-r04/assembled-preview.png

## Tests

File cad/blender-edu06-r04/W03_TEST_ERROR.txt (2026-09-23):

Traceback (most recent call last):
  File "C:\Users\hpone\OneDrive\Documents\ChatGPT\Educational Manipulator\cad\blender-edu06-r04\test_w03.py", line 14, in <module>
    L.ROOT=ROOT/'w03-test';L.ROOT.mkdir(exist_ok=True);L.export_parts()
                                                       ~~~~~~~~~~~~~~^^
  File "C:\Users\hpone\OneDrive\Documents\ChatGPT\Educational Manipulator\cad\blender-edu06-r04\blender_lib.py", line 171, in export_parts
    bm=prepare_export_bmesh(o,list(o['print_rotation_deg']))
  File "C:\Users\hpone\OneDrive\Documents\ChatGPT\Educational Manipulator\cad\blender-edu06-r04\mesh_repair.py", line 95, in prepare_export_bmesh
    raise ValueError(o.name+': both triangulators produced degenerate or nonmanifold STL triangles')
ValueError: W03_moving_pitch_cradle: both triangulators produced degenerate or nonmanifold STL triangles

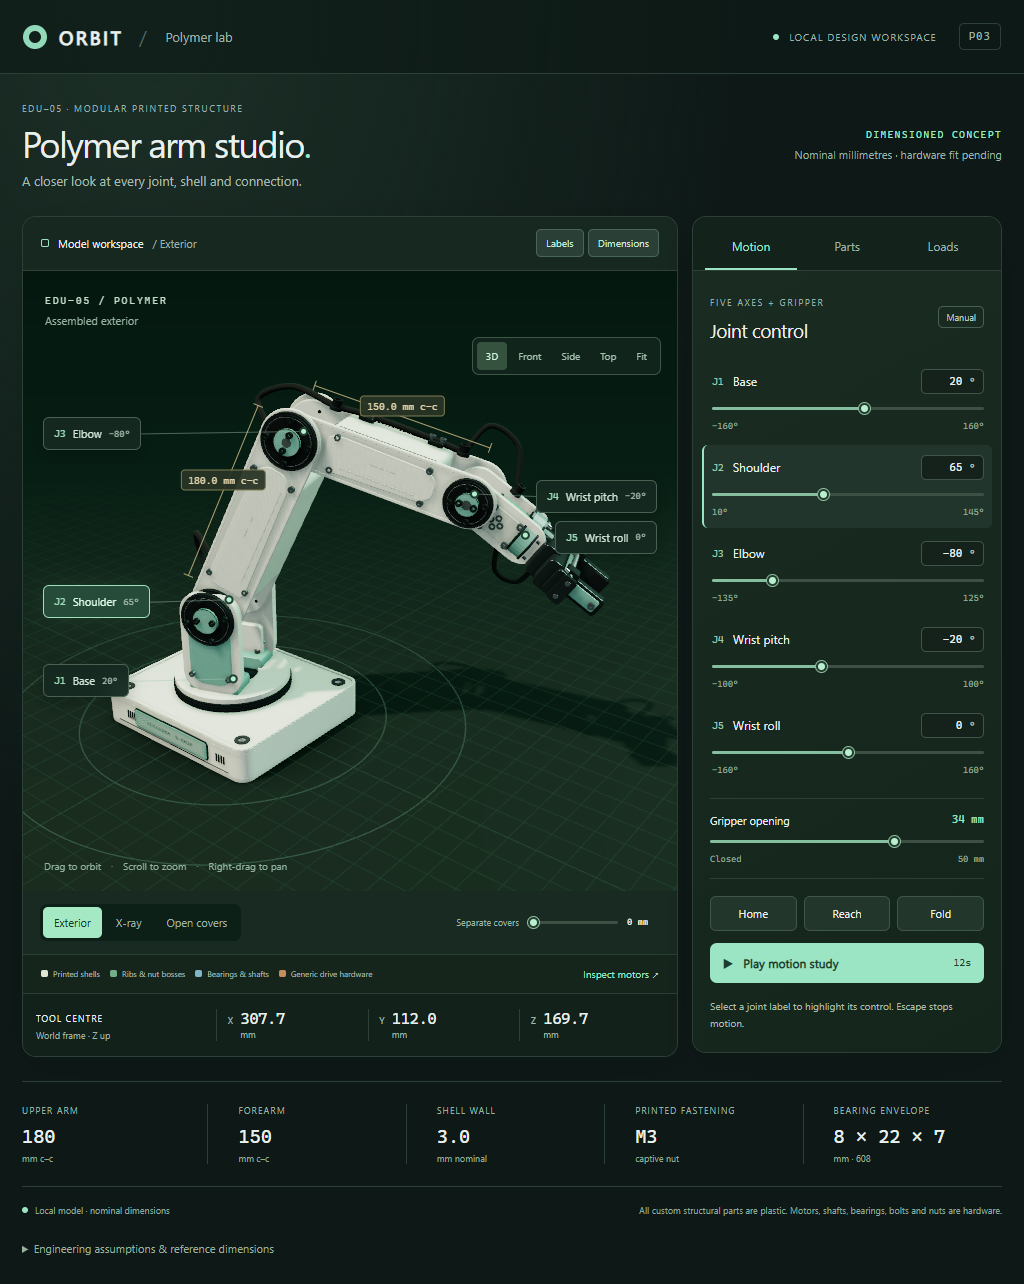
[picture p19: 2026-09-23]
polymer-studio/qa/width-1024.png

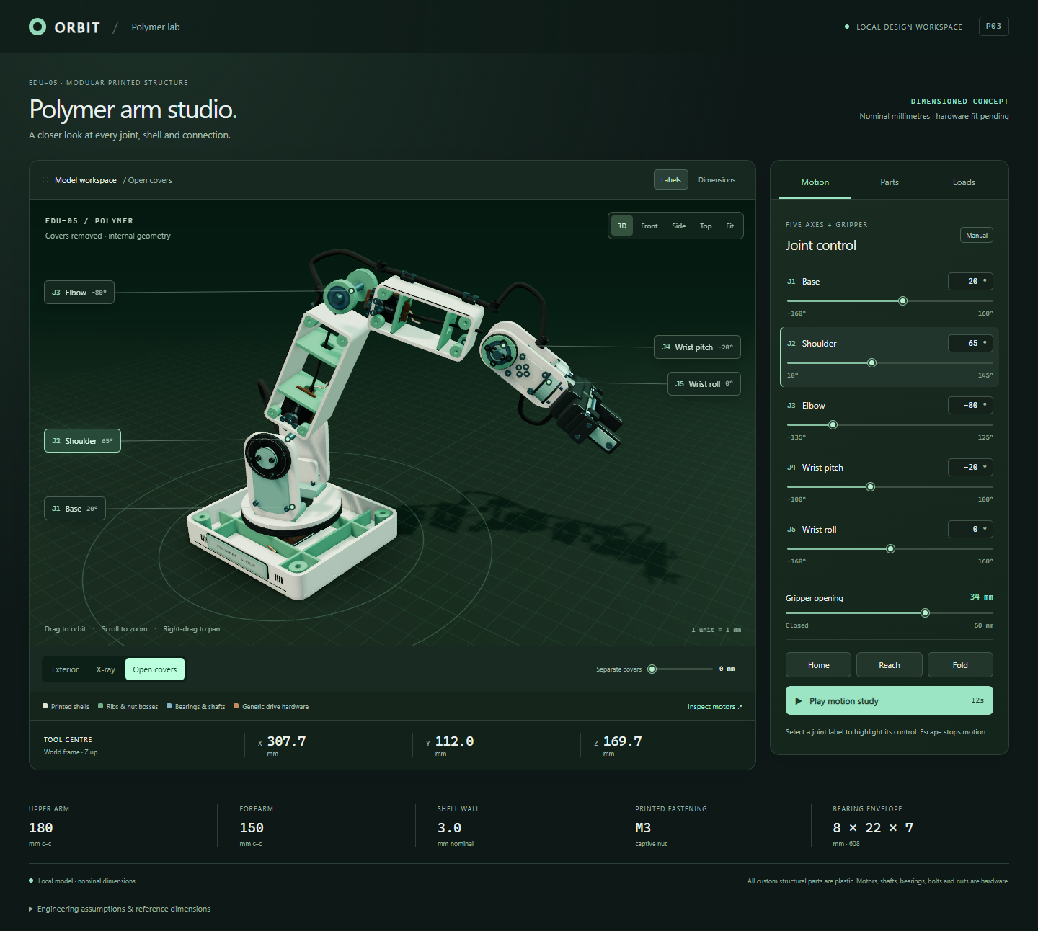
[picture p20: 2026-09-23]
polymer-studio/qa/open-covers.png

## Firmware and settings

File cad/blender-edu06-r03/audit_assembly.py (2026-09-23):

"""Read-only independent Blender mass/kinematic/collision screening of EDU06 R03.

Launch with Blender --background --python audit_assembly.py. Does not save the
opened .blend and never edits the builder. Optional args after --: --blend PATH,
--output PATH, --home-only (quick collision diagnostic, not full pose coverage).
"""
from __future__ import annotations

import argparse
from datetime import datetime, timezone
import itertools
import json
import math
from pathlib import Path
import re
import sys
import time

import bpy
import numpy as np
from mathutils import Vector
from mathutils.bvhtree import BVHTree


ROOT = Path(__file__).resolve().parent
PLA_DENSITY_G_MM3 = 0.00124
GRAVITY_M_S2 = 9.81
ALLOWANCE = 1.10
MOTOR_SCREEN = {
    'J2': {'motor': 'XM430-W350-T', 'ratio': 4, 'efficiency': .65, 'comparison_nm': .82},
    'J3': {'motor': 'XM430-W350-T', 'ratio': None, 'efficiency': .65, 'comparison_nm': .82},
    'J4': {'motor': 'AX-12A', 'ratio': 1, 'efficiency': .85, 'comparison_nm': .30},
    'J5': {'motor': 'AX-12A', 'ratio': 1, 'efficiency': .85, 'comparison_nm': .30},
    'J6': {'motor': 'AX-12A', 'ratio': 1, 'efficiency': .85, 'comparison_nm': .30},
}


def say(message):
    print(message, flush=True)


def descendants_of(obj, ancestor):
    current = obj
    while current is not None:
        if current == ancestor:
            return True
        current = current.parent
    return False


def geometry(obj, depsgraph):
    evaluated = obj.evaluated_get(depsgraph)
    mesh = evaluated.to_mesh()
    try:
        mesh.calc_loop_triangles()
        vertices = np.array([v.co[:] for v in mesh.vertices], dtype=np.float64)
        triangles = np.array([t.vertices[:] for t in mesh.loop_triangles], dtype=np.int32)
    finally:
        evaluated.to_mesh_clear()
    if not len(vertices) or not len(triangles):
        raise ValueError(f'{obj.name}: empty evaluated mesh')
    if not np.isfinite(vertices).all():
        raise ValueError(f'{obj.name}: nonfinite coordinates')
    local_reference = (vertices.min(axis=0) + vertices.max(axis=0)) * .5
    local = vertices[triangles] - local_reference
    volumes = np.einsum('ij,ij->i', local[:, 0],
                       np.cross(local[:, 1], local[:, 2])) / 6.0
    volume = float(volumes.sum())
    centroid = (np.einsum('i,ij->j', volumes, local.sum(axis=1)) / (4 * volume)
                + local_reference) if abs(volume) > 1e-8 else vertices.mean(axis=0)
    return {'vertices': vertices, 'triangles': triangles,
            'signed_volume_local_mm3': volume, 'centroid_local': Vector(centroid)}


def find_controls():
    controllers = [obj for obj in bpy.data.objects if obj.name.startswith('CONTROL')
                   and all(key in obj for key in ('J1', 'J2', 'J3', 'J4', 'J5', 'J6'))]
    if len(controllers) != 1:
        raise RuntimeError(f'Expected one CONTROL with J1-J6 properties, found {len(controllers)}')
    joints = {}
    for key in ('J1', 'J2', 'J3', 'J4', 'J5', 'J6'):
        candidates = [obj for obj in bpy.data.objects if obj.name.startswith(key + ' ')
                      and obj.get('axis') == 'LOCAL Z' and 'DATUM' not in obj.name]
        if len(candidates) != 1:
            raise RuntimeError(f'Cannot uniquely identify {key} actual output axis: {len(candidates)}')
        joints[key] = candidates[0]
    return controllers[0], joints


def set_pose(controller, pose):
    for key, value in pose.items():
        controller[key] = float(value)
    controller.update_tag(refresh={'OBJECT'})
    bpy.context.view_layer.update()
    bpy.context.evaluated_depsgraph_get().update()


def world_matrix(obj):
    return obj.evaluated_get(bpy.context.evaluated_depsgraph_get()).matrix_world.copy()


def make_poses(controller, joints):
    home = {key: float(joints[key].get('home_deg', controller[key])) for key in joints}
    if 'GRIP' in controller:
        home['GRIP'] = float(controller['GRIP'])
    limits = {key: [float(x) for x in joints[key].get('limits_deg', [-180, 180])]
              for key in joints}
    if 'GRIP' in controller:
        ui = controller.id_properties_ui('GRIP').as_dict()
        limits['GRIP'] = [float(ui.get('min', 0)), float(ui.get('max', 24))]
    horizontal = {**home, 'J1': 0., 'J2': 0., 'J3': 0., 'J4': 0., 'J5': 0., 'J6': 0.}
    poses = [('home', home), ('horizontal_stress_case', horizontal)]
    for key in limits:
        for end, value in zip(('min', 'max'), limits[key]):
            poses.append((key + '_' + end, {**home, key: value}))
    for name, lo_hi in [('combined_low', 0), ('combined_high', 1)]:
        poses.append((name, {**home, **{key: bounds[lo_hi] for key, bounds in limits.items()}}))
    return poses, limits


def outside_limits(pose, limits):
    return {key: value for key, value in pose.items()
            if key in limits and not (limits[key][0] - 1e-8 <= value <= limits[key][1] + 1e-8)}


def fingertip_midpoint(cache):
    tips = []
    for prefix in ('G05_', 'G06_'):
        candidates = [(obj, data) for obj, data in cache.items() if obj.name.startswith(prefix)]
        if len(candidates) != 1:
            raise RuntimeError(f'Cannot identify one gripper jaw with prefix {prefix}')
        obj, data = candidates[0]
        points = data['vertices']
        # Jaw construction's longest local +X extent is the fingertip; using a
        # small end strip avoids mistaking its circular gear rim for a contact.
        end_strip = points[points[:, 0] >= points[:, 0].max() - 3.0]
        tip = world_matrix(obj) @ Vector(end_strip.mean(axis=0))
        tips.append({'object': obj.name, 'point_world_mm': list(tip)})
    midpoint = sum((Vector(tip['point_world_mm']) for tip in tips), Vector()) / len(tips)
    return midpoint, tips


def read_gear_specs(blend_path):
    path = blend_path.parent / 'gear-pairs.json'
    specs = json.loads(path.read_text(encoding='utf-8'))
    by_name = {item['name']: item for item in specs}
    for key in ('J2', 'J3'):
        teeth = by_name[key]['teeth']
        if len(teeth) != 2 or not all(float(value) > 0 for value in teeth):
            raise ValueError(f'{key}: invalid tooth counts in {path}')
        MOTOR_SCREEN[key]['ratio'] = float(teeth[1]) / float(teeth[0])
    return by_name, {
        'path': str(path.resolve()),
        'modified_utc': datetime.fromtimestamp(path.stat().st_mtime, timezone.utc).isoformat(),
        'specifications': specs,
        'note': 'Mass torque reductions read from this sidecar; evaluated driver checks below verify its ratio against the opened blend.',
    }


def audit_controls(controller, joints, cache, home, limits, gear_specs):
    """Sample three numerical values for each control, including actual output."""
    palm_candidates = [obj for obj in bpy.data.objects if obj.name.startswith('GRIPPER fixed palm datum')]
    if len(palm_candidates) != 1:
        raise RuntimeError('Expected exactly one fixed gripper palm datum for tool-transform tests')
    palm = palm_candidates[0]
    rows = []
    for key, bounds in limits.items():
        samples = []
        for value in (bounds[0], (bounds[0] + bounds[1]) * .5, bounds[1]):
            set_pose(controller, {**home, key: value})
            midpoint, tips = fingertip_midpoint(cache)
            matrix = world_matrix(palm)
            sample = {
                'requested_degrees': value, 'fingertip_midpoint_world_mm': list(midpoint),
                'fingertip_gap_mm': float((Vector(tips[0]['point_world_mm']) - Vector(tips[1]['point_world_mm'])).length),
                'tool_origin_world_mm': list(matrix.translation),
                'tool_orientation_quaternion': list(matrix.to_quaternion()),
            }
            if key in joints:
                actual = math.degrees(joints[key].evaluated_get(bpy.context.evaluated_depsgraph_get()).rotation_euler.z)
                sample['actual_output_degrees'] = actual
                sample['output_angle_error_degrees'] = actual - value
            if key in ('J1', 'J2', 'J3'):
                spec = gear_specs[key]
                motor_node = bpy.data.objects.get(spec['pinion'])
                if motor_node is None:
                    raise RuntimeError(f'{key}: pinion object from sidecar is missing')
                ratio = float(spec['teeth'][1]) / float(spec['teeth'][0])
                phase = math.degrees(float(spec['pinion_phase_rad']))
                measured = math.degrees(motor_node.evaluated_get(bpy.context.evaluated_depsgraph_get()).rotation_euler.z)
                expected = phase - ratio * value
                sample.update({'gear_ratio_from_teeth': ratio, 'actual_pinion_degrees': measured,
                               'expected_pinion_degrees': expected, 'pinion_angle_error_degrees': measured - expected})
            if key == 'GRIP':
                lower = bpy.data.objects.get('GRIP lower driven jaw')
                upper = bpy.data.objects.get('GRIP upper idler jaw')
                if lower is None or upper is None:
                    raise RuntimeError('Missing named gripper-jaw driver empties')
                graph = bpy.context.evaluated_depsgraph_get()
                lower_deg = math.degrees(lower.evaluated_get(graph).rotation_euler.z)
                upper_deg = math.degrees(upper.evaluated_get(graph).rotation_euler.z)
                sample.update({'actual_lower_jaw_degrees': lower_deg, 'actual_upper_jaw_degrees': upper_deg,
                               'jaw_error_degrees': max(abs(lower_deg + value), abs(upper_deg - value))})
            samples.append(sample)
        start, finish = samples[0], samples[-1]
        positional_change = float((Vector(start['fingertip_midpoint_world_mm']) - Vector(finish['fingertip_midpoint_world_mm'])).length)
        from mathutils import Quaternion
        q_start = Quaternion(start['tool_orientation_quaternion'])
        q_finish = Quaternion(finish['tool_orientation_quaternion'])
        angular_change = math.degrees(q_start.rotation_difference(q_finish).angle)
        gap_change = abs(start['fingertip_gap_mm'] - finish['fingertip_gap_mm'])
        follows_requested_angles = all(abs(sample.get('output_angle_error_degrees', 0)) < .001 and
                                      abs(sample.get('pinion_angle_error_degrees', 0)) < .001 and
                                      abs(sample.get('jaw_error_degrees', 0)) < .001 for sample in samples)
        affects_tool = gap_change > .01 if key == 'GRIP' else (positional_change > .01 or angular_change > .001)
        rows.append({'control': key, 'samples': samples,
                     'fingertip_midpoint_change_mm': positional_change,
                     'tool_orientation_change_degrees': angular_change,
                     'fingertip_gap_change_mm': gap_change,
                     'evaluated_angles_follow_requested_control_and_gear_ratio': follows_requested_angles,
                     'affects_end_effector_pose_or_grip': affects_tool,
                     'pass': follows_requested_angles and affects_tool})
    set_pose(controller, home)
    return {'all_passed': all(row['pass'] for row in rows), 'control_count': len(rows),
            'samples_per_control': 3, 'tests': rows,
            'scope': 'Checks evaluated numerical motion and gear-driver ratios; does not establish contact mechanics, free movement or motor capability.'}


def mass_inventory(cache, joints):
    inventory = []
    for obj, data in cache.items():
        is_printed = bool(obj.get('part_id'))
        if obj.name.startswith(('F0', 'B03_')):
            continue
        if not is_printed and float(obj.get('mass_g', 0)) <= 0:
            continue
        scale = abs(world_matrix(obj).to_3x3().determinant())
        volume = data['signed_volume_local_mm3'] * scale
        mass = abs(volume) * PLA_DENSITY_G_MM3 if is_printed else float(obj['mass_g'])
        inventory.append({
            'object': obj.name, 'obj': obj, 'mass_g': mass,
            'source': 'solid_mesh_PLA_1.24g_per_cm3' if is_printed else 'motor_or_electronics_reference_mass',
            'printed': is_printed, 'signed_solid_volume_mm3': volume if is_printed else None,
            'positive_mesh_volume': volume > 0,
            'centroid_local_mm': list(data['centroid_local']),
            'descendant_of': [key for key, joint in joints.items() if descendants_of(obj, joint)],
            'rigid_group': str(obj.get('rigid_group', 'UNSTAMPED')),
        })
    return inventory


def load_case(inventory, joints, payload_g, payload_point):
    rows = {}
    for key, screening in MOTOR_SCREEN.items():
        axis_matrix = world_matrix(joints[key])
        origin = axis_matrix.translation
        axis = (axis_matrix.to_3x3() @ Vector((0, 0, 1))).normalized()
        torque_vector = Vector()
        unallowed_torque_vector = Vector()
        mass_g = 0.
        for item in inventory:
            if key not in item['descendant_of']:
                continue
            centre = world_matrix(item['obj']) @ Vector(item['centroid_local_mm'])
            force = Vector((0, 0, -GRAVITY_M_S2 * item['mass_g'] / 1000.))
            moment = ((centre - origin) / 1000.).cross(force)
            unallowed_torque_vector += moment
            torque_vector += moment * ALLOWANCE
            mass_g += item['mass_g']
        payload_moment = ((payload_point - origin) / 1000.).cross(
            Vector((0, 0, -GRAVITY_M_S2 * payload_g / 1000.)))
        torque_vector += payload_moment
        actual_axis_torque = float(torque_vector.dot(axis))
        gravity_motor = abs(actual_axis_torque) / (screening['ratio'] * screening['efficiency'])
        dynamic_screen = gravity_motor * 1.5
        rows[key] = {
            **screening, 'axis_origin_world_mm': list(origin), 'axis_unit_world': list(axis),
            'descendant_mass_g_before_allowance': mass_g,
            'descendant_mass_g_with_10percent_allowance': mass_g * ALLOWANCE,
            'gravity_axis_torque_without_allowance_or_payload_nm': float(unallowed_torque_vector.dot(axis)),
            'payload_axis_torque_nm': float(payload_moment.dot(axis)),
            'gravity_axis_torque_with_allowance_and_payload_nm': actual_axis_torque,
            'total_gravity_bending_vector_nm': list(torque_vector),
            'total_gravity_bending_vector_magnitude_nm': float(torque_vector.length),
            'estimated_motor_gravity_torque_nm': gravity_motor,
            'motor_gravity_to_comparison_ratio': gravity_motor / screening['comparison_nm'],
            'gravity_exceeds_estimated_motor_comparison': gravity_motor > screening['comparison_nm'],
            'motor_torque_with_arbitrary_1p5_allowance_nm': dynamic_screen,
            'one_point_five_case_exceeds_comparison': dynamic_screen > screening['comparison_nm'],
        }
    return {'payload_g': payload_g, 'payload_point_world_mm': list(payload_point), 'joints': rows}


def collision_objects(cache):
    return [(obj, data) for obj, data in cache.items()
            if not obj.name.startswith(('F0', 'B03_')) and
            (bool(obj.get('part_id')) or bool(obj.get('collision_check', False)))]


def static_stability(inventory, payload_point, payload_g=25.0):
    total_mass = payload_g
    moment = payload_point * payload_g
    for item in inventory:
        factor = ALLOWANCE if item['descendant_of'] else 1.0
        mass = item['mass_g'] * factor
        centre = world_matrix(item['obj']) @ Vector(item['centroid_local_mm'])
        total_mass += mass
        moment += centre * mass
    centre = moment / total_mass
    edge_margins = {'x_negative': float(centre.x + 108), 'x_positive': float(108 - centre.x),
                    'y_negative': float(centre.y + 73), 'y_positive': float(73 - centre.y)}
    margin = min(edge_margins.values())
    return {
        'payload_g': payload_g, 'total_modelled_mass_g': total_mass,
        'combined_COM_world_mm': list(centre),
        'support_polygon_foot_centres_world_xy_mm': [[-108,-73],[108,-73],[108,73],[-108,73]],
        'signed_distances_to_support_edges_mm': edge_margins,
        'minimum_signed_margin_mm': margin, 'static_projection_inside_support_polygon': margin >= 0,
        'smallest_gravity_restoring_moment_about_support_edge_nm': total_mass / 1000 * GRAVITY_M_S2 * margin / 1000,
        'bench_anchorage_assumed': False,
        'note': 'Static level-table model only, using solid PLA mesh mass and moving 10% allowance. No acceleration, cable pull, friction/sliding, compliance or reduced-infill mass model. Removed front panel and all F0 fit coupons are excluded.',
    }


def canonical_rigid_group(obj):
    """A fixed DATUM does not create a rigid body; nearest actuated parent does."""
    current = obj
    while current is not None:
        animation = current.animation_data
        if animation and any(curve.data_path == 'rotation_euler' for curve in animation.drivers):
            return current.name
        current = current.parent
    return 'FIXED'


def prepare_world_collision(obj, data):
    matrix = np.array(world_matrix(obj), dtype=np.float64)
    vertices = data['vertices'] @ matrix[:3, :3].T + matrix[:3, 3]
    triangles = data['triangles']
    tree = BVHTree.FromPolygons([tuple(v) for v in vertices], [tuple(t) for t in triangles],
                               all_triangles=True, epsilon=0.0)
    triangle_vertices = vertices[triangles]
    normals = np.cross(triangle_vertices[:, 1] - triangle_vertices[:, 0],
                       triangle_vertices[:, 2] - triangle_vertices[:, 0])
    lengths = np.linalg.norm(normals, axis=1)
    normals = normals / np.maximum(lengths[:, None], 1e-15)
    return {'object': obj, 'vertices': vertices, 'triangles': triangles, 'normals': normals,
            'tree': tree, 'lower': vertices.min(axis=0), 'upper': vertices.max(axis=0),
            'group': canonical_rigid_group(obj)}


RAY_DIRECTIONS = [Vector(value).normalized() for value in
                  ((1., .37139067, .17320508), (-.219381, 1., .419771), (.349273, -.167281, 1.))]


def is_inside(tree, point):
    """Majority parity of three rays; 0.005 mm advances avoid float32 re-hits."""
    votes = 0
    any_limited = False
    for direction in RAY_DIRECTIONS:
        origin = Vector(point)
        hits = 0
        limited = True
        for _ in range(160):
            hit, normal, index, distance = tree.ray_cast(origin, direction)
            if hit is None:
                limited = False
                votes += int(bool(hits % 2))
                break
            hits += 1
            origin = hit + direction * .005
        any_limited |= limited
    return votes >= 2, any_limited


def test_ray_parity():
    vertices = [(0,0,0),(1,0,0),(1,1,0),(0,1,0),(0,0,1),(1,0,1),(1,1,1),(0,1,1)]
    triangles = [(0,2,1),(0,3,2),(4,5,6),(4,6,7),(0,1,5),(0,5,4),
                 (1,2,6),(1,6,5),(2,3,7),(2,7,6),(3,0,4),(3,4,7)]
    tree = BVHTree.FromPolygons(vertices, triangles, all_triangles=True, epsilon=0.0)
    for point in ((.5,.5,.5),(.1,.2,.3),(.95,.99,.01)):
        assert is_inside(tree, point) == (True, False), ('cube inside', point)
    for point in ((-1,.5,.5),(2,.5,.5),(.5,.5,2),(.5,.5,-2)):
        assert is_inside(tree, point) == (False, False), ('cube outside', point)
    # Closed annular prism: the central bore is empty despite lying inside AABB.
    n = 40
    verts = [(radius*math.cos(2*math.pi*i/n), radius*math.sin(2*math.pi*i/n), z)
             for z in (0., 2.) for radius in (2., 1.) for i in range(n)]
    quads = []
    for i in range(n):
        k = (i+1) % n
        quads += [(i,k,2*n+k,2*n+i),(n+k,n+i,3*n+i,3*n+k),
                  (i,n+i,n+k,k),(2*n+k,3*n+k,3*n+i,2*n+i)]
    ring = BVHTree.FromPolygons(verts, quads, all_triangles=False, epsilon=0.0)
    assert is_inside(ring, (0.,0.,1.)) == (False, False), 'ring bore must be empty'
    assert is_inside(ring, (1.5,0.,1.)) == (True, False), 'ring wall must be solid'
    from mathutils import Matrix
    for degrees in (-85, -40, 40, 85):
        transform = Matrix.Translation((120., -80., 310.)) @ Matrix.Rotation(math.radians(degrees),4,'Z') @ Matrix.Rotation(.632,4,'X')
        moved = BVHTree.FromPolygons([transform @ Vector(vertex) for vertex in verts], quads,
                                     all_triangles=False, epsilon=0.0)
        for point, expected in (((0.,0.,1.), False), ((1.5,0.,1.), True), ((3.,0.,1.), False)):
            assert is_inside(moved, transform @ Vector(point)) == (expected, False), ('rotated ring',degrees,point)
    say('PASS: independent ray-parity cube, hollow-sleeve and translated/rotated-sleeve tests')
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

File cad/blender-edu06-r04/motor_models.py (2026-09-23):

"""Dimensioned DYNAMIXEL references and separately printable captured cradles.

All coordinates are millimetres.  Origin is the front face of the installed horn,
with the motor output axis along local +Z; the case height follows local Y.
Purchased motor surfaces are tessellated directly from official ROBOTIS STEP CAD.
XM internal case/horn separation is added solely to animate the vendor dummy exterior.
"""
import math, bmesh, bpy, gzip, json
from pathlib import Path
from mathutils import Matrix, Euler
import blender_lib as L


MOTOR_UNITS=[]


SPECS = {
    'AX': dict(model='AX-12A', width=32.0, height=50.0, top=11.5,
               case_front=-5.0, case_back=-37.0, rear=-40.0, rear_seat=-37.0,
               horn_depth=5.0, horn_diameter=22.0, horn_count=4, horn_pcd=16.0,
               mass=54.6, bezel_back=-4.65, bezel_front=-1.05, rear_shim=3.30),
    'XM': dict(model='XM430-W350-T', width=28.5, height=46.5, top=11.25,
               case_front=-2.0, case_back=-36.0, rear=-36.2, rear_seat=-36.0,
               horn_depth=2.0, horn_diameter=19.5, horn_count=8, horn_pcd=16.0,
               mass=82.0, bezel_back=-1.65, bezel_front=-.25, rear_shim=.50),
}


def _label(name, body, pos, size, mat, parent, tf, rotation=(0, 0, 0)):
    o=L.text(name,body,(0,0,0),size,mat)
    o.parent=parent
    o.matrix_parent_inverse=Matrix.Identity(4)
    o.matrix_basis=tf @ L.T(*pos) @ Euler(rotation).to_matrix().to_4x4()
    o['reference_only']=True
    return o


_CAD_CACHE={}
_VENDOR_MESH_CACHE={}


def _vendor_close_tessellation(o):
    # Weld analytic-face boundaries within ONE vendor solid. Never weld two
    # touching purchased components together: that creates nonmanifold edges.
    bm=bmesh.new();bm.from_mesh(o.data)
    bmesh.ops.remove_doubles(bm,verts=list(bm.verts),dist=.000001)
    bmesh.ops.recalc_face_normals(bm,faces=list(bm.faces))
    bm.to_mesh(o.data);bm.free();o.data.update()
    return o


def _retain_ax_front_seating_piece(o):
    """Remove only disconnected upper-corner chips from the AX front shim.

    The Ø34 access opening leaves one functional U-shaped front seating piece
    and two tiny isolated corner remnants. The retained vertices are unchanged;
    this does not bridge the opening or alter the motor clearance.
    """
    bm=bmesh.new();bm.from_mesh(o.data)
    before=bm.calc_volume(signed=True)
    remaining=set(bm.verts);components=[]
    while remaining:
        seed=remaining.pop();component={seed};pending=[seed]
        while pending:
            vertex=pending.pop()
            for edge in vertex.link_edges:
                neighbour=edge.other_vert(vertex)
                if neighbour in remaining:
                    remaining.remove(neighbour);component.add(neighbour);pending.append(neighbour)
        components.append(component)
    if len(components)>1:
        def surface_area(component):
            return sum(face.calc_area() for face in {f for v in component for f in v.link_faces})
        retained=max(components,key=surface_area)
        discarded=[v for component in components if component is not retained for v in component]
        bmesh.ops.delete(bm,geom=discarded,context='VERTS')
    bmesh.ops.recalc_face_normals(bm,faces=list(bm.faces))
    after=bm.calc_volume(signed=True)
    bm.to_mesh(o.data);bm.free();o.data.update()
    o['disconnected_nonfunctional_corners_removed']=max(0,len(components)-1)
    o['removed_corner_volume_mm3']=before-after
    o['front_seating_shape']='Single connected U; side and lower case flange contact; upper casing remains open.'
    return o


def _vendor_mesh(name, vertices, faces, mat):
    data=bpy.data.meshes.new(name)
    data.from_pydata(vertices,[],faces);data.update()
    o=bpy.data.objects.new(name,data);bpy.context.scene.collection.objects.link(o)
    data.materials.append(mat)
    _vendor_close_tessellation(o)
    # STEP tessellation retains vertices split at analytic surface boundaries.
    for p in data.polygons:p.use_smooth=True
    return o


def _join_vendor(objects,name):
    target=objects[0];L.active(target)
    for o in objects:o.select_set(True)
    bpy.ops.object.join();target.name=name
    return target


def _xm_partition(o,upper):
    """Partition the closed vendor exterior, retaining all external vertices."""
    bm=bmesh.new();bm.from_mesh(o.data)
    bmesh.ops.bisect_plane(bm,geom=list(bm.verts)+list(bm.edges)+list(bm.faces),
        dist=.00001,plane_co=(0,0,-2),plane_no=(0,0,1),
        clear_inner=upper,clear_outer=not upper)
    if upper:
        # Coplanar front-case triangles belong to the fixed casing. Removing
        # them from the rotor leaves only the actual Ø19.5 horn above the plane.
        flat=[f for f in bm.faces if all(abs(v.co.z+2)<.00001 for v in f.verts)]
        bmesh.ops.delete(bm,geom=flat,context='FACES')
    bmesh.ops.dissolve_degenerate(bm,edges=list(bm.edges),dist=.000001)
    bmesh.ops.triangle_fill(bm,edges=[e for e in bm.edges if e.is_boundary],
                           use_beauty=True,use_dissolve=False)
    bmesh.ops.dissolve_degenerate(bm,edges=list(bm.edges),dist=.000001)
    bmesh.ops.recalc_face_normals(bm,faces=list(bm.faces))
    if any(not e.is_manifold for e in bm.edges):
        bm.free();raise RuntimeError('XM vendor partition must remain closed')
    bm.to_mesh(o.data);bm.free();o.data.update()
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
